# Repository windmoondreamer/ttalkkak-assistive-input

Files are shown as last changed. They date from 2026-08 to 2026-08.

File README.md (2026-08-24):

# OneGrip Play

한 손으로 PC 게임, Nintendo Switch, 웹 서핑과 미디어 조작을 할 수 있도록 만든 보조 입력기입니다. 손목·팔, 엄지, 검지·중지에 서로 다른 역할을 배분해 한 손 안에서 이동, 시점 조작, 버튼 입력을 함께 수행하는 것을 목표로 합니다.

> 현재 상태: 주요 기구부의 CAD와 자동 형상 검증, 전자부품 서비스 카세트, 전시용 A1 포스터까지 제작했습니다. 최종 실물 조립, 펌웨어 통합, 반복 내구시험과 대상 사용자 평가는 아직 진행해야 합니다.

<p align="center">
  OneGrip Play A1 전시 포스터
</p>

## 1. 개발 배경

양손 게임패드나 키보드·마우스는 이동, 시점, 액션 입력을 양손에 나눠 배치합니다. 다음과 같은 사용자는 손가락과 엄지를 움직일 수 있어도 이 입력들을 동시에 수행하기 어렵습니다.

- 편마비 또는 한쪽 상지의 기능 제한이 있는 사용자
- 한쪽 상지 절단으로 한 손 입력이 필요한 사용자
- 하반신 마비 등으로 침상이나 리클라이닝 자세에서 활동하는 사용자
- 팔을 넓게 움직이거나 양손 기기를 안정적으로 지지하기 어려운 사용자

OneGrip Play는 재활 효과를 주장하는 의료기기가 아니라, 게임과 디지털 여가에 접근할 수 있도록 돕는 보조 입력기 시제품입니다.

## 2. 현재 채택한 입력 구조

| 사용하는 부위 | 입력 장치 | PC 게임·Switch | 웹·미디어 |
|---|---|---|---|
| 손목·팔 | 하단 2축 짐벌 | 캐릭터 이동 | 메뉴 탐색 |
| 엄지 | 소형 조이스틱 | 시점 조작 | 포인터 이동·스크롤 |
| 검지·중지 | 8개 손가락 버튼 | 주요 액션 | 클릭·재생 제어 |

핵심은 입력 수를 무작정 늘리는 것이 아니라, 사용자가 이미 구분하기 쉬운 세 동작에 기능을 나누는 것입니다. 현재 통합안은 초기의 전체 QWERTY·트랙볼 구조가 아니라 **게임과 미디어에 필요한 핵심 입력을 우선한 구조**입니다.

## 3. 설계가 바뀐 과정

### 3.1 버티컬 키보드·트랙볼 탐색

처음에는 버티컬 마우스형 그립에 전체 문자 키와 엄지 트랙볼을 결합하는 방향을 검토했습니다. Half-QWERTY, 전체 물리 자판, U자형 키타워, 손가락별 3방향 스위치와 엄지 보조키 등 여러 배치를 비교했습니다.

그러나 전체 문자를 작은 그립에 넣으면 다음 문제가 생겼습니다.

- 키가 작아지고 인접 입력 가능성이 커짐
- 새로운 배열과 레이어 전환을 학습해야 함
- 손가락 독립성이 낮은 사용자에게 조작 부담이 커짐
- 멘토링에서 “적응하기 어려워 보인다”는 피드백을 받음

### 3.2 조종간형 뱅크 전환 탐색

본체를 좌우로 기울여 Bank A/B를 전환하고, 각 손가락에 좌·중앙·우 입력을 배치하는 조종간형 구조도 검토했습니다. 손가락 길이 차이, 지문 접촉 위치, 손바닥 지지, 중수골 스트랩, 엄지 도달 범위를 렌더로 반복 수정했습니다.

이 구조는 많은 문자를 넣을 수 있었지만 학습량과 기구 복잡도가 다시 증가했습니다. 이후 제품 목적을 문자 입력기에서 게임·미디어 보조 컨트롤러로 좁혔습니다.

### 3.3 OneGrip Play로 범위 축소

현재는 다음 원칙을 적용합니다.

1. 전체 키보드를 넣지 않는다.
2. PC 게임과 Nintendo Switch의 이동·시점·주요 액션을 우선한다.
3. 웹 서핑과 유튜브·OTT에 필요한 포인터·스크롤·클릭·재생 기능을 함께 제공한다.
4. 별도의 복잡한 문자 Bank 대신 기능 프로필로 입력을 매핑한다.
5. 커스텀 PCB 없이 완제품 개발보드와 직접 배선으로 시제품을 제작한다.

## 4. 인체공학 설계 기준

- 팔받침 각도: **20°**
- 손목만으로 기기를 지탱하지 않도록 전완 지지면을 넓게 구성
- 손을 퍼티에 쥔 듯한 곡면을 기준으로 손바닥과 손가락 접촉면 형성
- 손가락 길이 차이를 반영해 검지·중지 입력 위치를 다르게 배치
- 버튼을 누르기 위해 그립에서 손가락을 크게 떼지 않도록 구성
- 입력부를 교체 가능한 카세트로 분리해 손 크기와 스위치 공차를 조정 가능하게 설계

이 항목들은 CAD 설계 기준입니다. “인체공학적으로 최적”하다고 확정하려면 대상 사용자의 실제 손 자세, 압력 분포, 도달률과 피로도 시험이 필요합니다.

## 5. 기구 설계

### 5.1 검지·중지 8버튼 카세트

현재 통합 모듈은 검지 4키와 중지 4키로 구성됩니다.

- 기존 손가락 곡률과 버튼 중심을 유지
- 버튼 캡이 손가락 표면의 법선 방향으로 움직이도록 가이드 적용
- 검지와 중지를 각각 메인 3키와 측면 1키로 분리
- 깊은 스위치 홀더 대신 얕은 receiver와 내부 carrier 사용
- ITS-1105 실측값을 기준으로 스위치 포켓에 측면 여유 확보
- 공통 TPU rear pad로 스위치 후면을 지지
- FDM 출력 전 공차 쿠폰으로 스위치와 캡 끼워맞춤을 먼저 확인

자세한 제작 순서는 [`cad/onegrip-index-middle-cassette-v2/README.md`](cad/onegrip-index-middle-cassette-v2/README.md)에 정리했습니다.

### 5.2 3방향 손가락 모듈 연구안

별도 연구 브랜치에서는 검지·중지·약지·소지 각각에 LEFT/CENTER/RIGHT 독립 입력을 배치했습니다. 하나의 로커를 세 방향으로 쓰지 않고, 중앙 직선 플런저와 좌우 독립 회전 패들을 분리한 구조입니다.

최신 자동 검증 결과는 다음과 같습니다.

| 검증 항목 | 결과 |
|---|---:|
| 모듈 내부 최대 교차 부피 | 0.2787 mm³ |
| 인접 손가락 모듈 간 교차 부피 | 0.0 mm³ |
| B-rep 유효성 | 전 부품 통과 |
| hard stop 검증 | 4손가락 통과 |
| 종합 판정 | `overall_pass: true` |

이 결과는 CAD 형상 검증이며, 실제 입력 정확도나 피로도를 증명하지 않습니다. 자료는 [`cad/finger-input-v2-ergonomic/`](cad/finger-input-v2-ergonomic/)에 있습니다.

### 5.3 하부 2축 짐벌

하부 짐벌은 손잡이 전체를 움직여 이동 또는 메뉴 탐색 입력을 만드는 구조입니다.

- 20° 기울어진 원본 하우징 좌표계를 월드 좌표에 맞춰 조립
- 고정부와 가동부를 Blender 부모 계층으로 분리
- Ring과 Hub를 서로 다른 축의 피벗으로 구성
- 현재 Full Module V3 기준 기구 이동 범위는 축별 ±10°
- 고정 베이스 바닥에서 `HAND_REF`까지 85.153 mm
- 경사 데크에서 `HAND_REF`까지 법선 방향 55.879 mm
- 피벗은 착좌면보다 18.5 mm 아래에 위치

38개 출력 STL은 모두 closed manifold로 확인했습니다. ±10° 조합 자세에서 계산한 표면점 최소거리는 모두 양수였지만, 이는 정확한 솔리드 Boolean 보증이 아니라 샘플링 기반 근사입니다. 베어링 저널, 나사 물림, 스프링, Hall 센서와 중력 보상은 추가 검증이 필요합니다.

전체 조립 자료는 [`cad/onegrip-full-module-v3/`](cad/onegrip-full-module-v3/)에서 확인할 수 있습니다.

## 6. 전자부품 서비스 카세트

커스텀 PCB는 사용하지 않습니다. RP2040-Zero와 전원보드를 같은 높이에 나란히 배치하고, 사람이 직접 조립·수리할 수 있는 단층 카세트를 만들었습니다.

| 항목 | 설계값 |
|---|---:|
| 카세트 조립 외형 | 36 × 45 × 14 mm |
| RP2040-Zero 실측 | 17.92 × 23.15 mm |
| RP2040 포켓 | 18.42 × 24.35 mm |
| 전원보드 | 15.35 × 23.24 mm |
| 보드 배치 | 단층·나란히 배치 |
| 뚜껑 체결 | M3 수직 나사 4개 |

주요 수정 내용은 다음과 같습니다.

- 기존 매립 트레이와 2층 적층안은 조립·정비가 어려워 폐기
- RP2040 길이 방향 여유를 끝당 0.60 mm로 확대
- 전원보드 외부 단자 개구 삭제
- 두 보드를 카세트 위에서 독립적으로 넣고 뺄 수 있도록 설계
- 카세트 본체는 고정 `Base` 전면에 연결하고 뚜껑은 별도 부품으로 유지
- 원본 Base의 불필요한 후면 돌출부와 중앙 벽을 제거하고 데크 상면 단차를 수정
- 스프링 고정 보스 4개와 움직이는 귀 4개를 보존

카세트와 뚜껑은 별도 솔리드이며 같은 출력판에서 함께 출력할 수 있습니다. 카세트 부착부는 스톡 짐벌의 축별·대각선 ±20° 검사에서 가동부와 계산상 교차 부피 0 mm³를 기록했습니다.

남은 STOP 조건은 전원보드 하부 부품의 실제 XY 위치, 최고 부품 높이, 실제 USB-C 플러그 외형과 케이블 굽힘 반경입니다. 자세한 내용은 [`cad/electronics_service_cassette/README.md`](cad/electronics_service_cassette/README.md)를 참고하십시오.

## 7. 전자·펌웨어 방향

- 메인 제어기: RP2040-Zero
- 제작 방식: 커스텀 PCB 없이 개발보드·모듈·직접 배선 사용
- 손가락 입력: 디지털 스위치 직접 배선 또는 입력 확장 모듈 검토
- 하부 짐벌과 엄지 조이스틱: 아날로그 축 입력
- 대상 환경: Windows PC, Nintendo Switch, 웹·미디어 제어

현재 저장소에는 기구 설계와 전자부품 배치 검토가 중심적으로 들어 있습니다. 최종 HID 펌웨어, 플랫폼별 프로필, 연결 안정성 및 장시간 시험은 완료 상태로 표시하지 않습니다.

## 8. 검증 현황

| 항목 | 현재 상태 | 남은 작업 |
|---|---|---|
| 대상 사용자·사용 시나리오 | 정의 완료 | 장애인 멘토 대상 추가 인터뷰와 과제 관찰 |
| 20° 팔받침 외형 | CAD 반영 | 손 크기별 파지·압력 시험 |
| 검지·중지 8버튼 | CAD·공차 설계 | 공차 쿠폰, 스위치 조립, 연타·오입력 시험 |
| 3방향 손가락 연구안 | 자동 형상 검증 통과 | 실제 복귀력·피로·정확도 시험 |
| 하부 2축 짐벌 | 조립·좌표계·가동 시각화 | 베어링/나사/스프링/센서 실물 검증 |
| 서비스 카세트 | CAD·간섭 검증 및 실물 피드백 반영 | 전원보드 부품 높이와 케이블 굽힘 반경 확정 |
| PC·Switch 입력 | 요구사항 정의 | 펌웨어·프로필·실기 연결 시험 |
| 웹·미디어 제어 | 기능 매핑 정의 | 포인터·스크롤·재생 시나리오 시험 |
| 전시 자료 | A1 포스터 제작 완료 | 최종 실물 사진과 사용자 시험 결과 반영 |

## 9. 저장소 구조

```text
.
├─ cad/
│  ├─ onegrip-full-module-v3/          전체 조립과 하부 짐벌
│  ├─ onegrip-index-middle-cassette-v2/ 검지·중지 8버튼 카세트
│  ├─ finger-input-v2-ergonomic/       4손가락 3방향 연구안
│  ├─ electronics_service_cassette/    RP2040·전원보드 카세트
│  ├─ stock-cartridge-option-c/        스톡 짐벌 카트리지 검토
│  └─ source_snapshot/                  팀원·Claude 최소 재현 원본
├─ analysis/                            부품 배치와 간섭 탐색 스크립트·결과
├─ docs/                                기구 분석, BOM, 시험 계획, 보고서
├─ references/                          Lalboard 재현용 잠금 정보와 가져오기 스크립트
├─ renders/                             초기 아이디어와 설계 탐색 렌더
├─ 전시포스터/                         A1 PPTX·PDF·PNG와 생성 스크립트
├─ 팀원공유용/                          팀 공유 압축본
├─ 계획및부품안.md                     초기 현실 구현안
├─ 완전구현_설계및부품안.md            전체 구현 검토안
└─ RP2040_전원보드_배치검토.md          전자부품 배치 결정 과정
```

`renders/`에는 채택하지 않은 트랙볼·키타워·뱅크 전환안도 포함되어 있습니다. 현재 채택안을 확인할 때는 `cad/onegrip-full-module-v3/`, `cad/onegrip-index-middle-cassette-v2/`, `cad/electronics_service_cassette/`를 우선하십시오.

### 작업본 계보

현재 통합본은 한 작업자가 처음부터 다시 만든 형상이 아닙니다.

| 출처 | 반영된 내용 | 현재 위치 |
|---|---|---|
| 팀원 최신 OneGrip 작업본 | 우측 상부 쉘, 기존 엄지 버튼·조이스틱, 기준 조립 좌표 | `cad/source_snapshot/team_claude_latest/` |
| Claude Code 체크포인트 | 검지·중지·엄지 구조 분석, 20° 하부 매립 짐벌과 검증 데이터 | 최소 원본 스냅숏과 `cad/onegrip-full-module-v3/` |
| 현재 통합·수정 작업 | 검지·중지 8버튼 V2, 짐벌 고정/가동 보정, 서비스 카세트, 포스터 | `cad/`, `analysis/`, `전시포스터/` |

GitHub에서 전체 모듈을 다시 만들 때 Desktop의 원래 작업 폴더가 없어도 되도록,
빌드에 실제로 필요한 18개 원본 파일을 저장소 내부에 포함했습니다. 자세한 범위와
해시는 [`cad/source_snapshot/team_claude_latest/README.md`](cad/source_snapshot/team_claude_latest/README.md)에 기록했습니다.

## 10. 주요 산출물

- 전체 모듈 패키지: [`OneGrip_Full_Module_RH_V3_EMBEDDED_GIMBAL.zip`](OneGrip_Full_Module_RH_V3_EMBEDDED_GIMBAL.zip)
- 검지·중지 카세트 패키지: [`OneGrip_IndexMiddle_Cassette_V2.zip`](OneGrip_IndexMiddle_Cassette_V2.zip)
- A1 전시 포스터: [`전시포스터/OneGrip_Play_A1_전시포스터.pdf`](전시포스터/OneGrip_Play_A1_전시포스터.pdf)
- 인쇄용 포스터 PNG: [`전시포스터/OneGrip_Play_A1_전시포스터_인쇄용.png`](전시포스터/OneGrip_Play_A1_전시포스터_인쇄용.png)
- 전자부품 배치 검토: [`RP2040_전원보드_배치검토.md`](RP2040_전원보드_배치검토.md)

대용량 ZIP은 소스와 중복되므로 Git 저장소에 계속 누적하기보다 GitHub Releases에 배포하는 편이 적합합니다.

## 11. 다음 단계

1. ITS-1105 공차 쿠폰과 검지 버튼 1세트를 먼저 출력합니다.
2. RP2040 길이 공차 쿠폰에서 끝당 0.50/0.60/0.70 mm를 실물 비교합니다.
3. 전원보드 상·하부 부품 높이와 USB 플러그 외형을 실측합니다.
4. 하부 짐벌의 베어링 저널, 나사 체결, 스프링과 센서 구조를 확정합니다.
5. RP2040 펌웨어에서 입력 스캔, 데드존, 디바운스와 플랫폼 프로필을 구현합니다.
6. PC와 Nintendo Switch에서 이동·시점·액션 동시 입력을 시험합니다.
7. 웹 서핑과 유튜브·OTT에서 포인터·스크롤·클릭·재생 과제를 시험합니다.
8. 장애인 멘토와 함께 도달 실패, 오입력, 피로, 통증 위치를 기록하고 손 크기별 부품을 수정합니다.

## 12. 참고 설계와 라이선스

손가락 입력 구조를 검토할 때 JesusFreke의 [Lalboard](https://github.com/JesusFreke/lalboard)를 참고했습니다. OneGrip의 CAD와 형상은 별도로 작성했으며 Lalboard 메시나 Python 형상을 복사하지 않았습니다.

재현 가능한 참조 커밋과 Apache License 2.0 고지는 다음 파일에 정리했습니다.

- [`NOTICE-THIRD-PARTY.md`](NOTICE-THIRD-PARTY.md)
- [`references/reference-lock.json`](references/reference-lock.json)
- [`THIRD_PARTY_LICENSES/lalboard-Apache-2.0.txt`](THIRD_PARTY_LICENSES/lalboard-Apache-2.0.txt)

저장소 전체에 적용할 프로젝트 라이선스는 별도로 확정해야 합니다. 제3자 고지 파일은 프로젝트 전체 라이선스를 대신하지 않습니다.

## 13. 팀

동국대학교 전자전기공학부  
김민섭 · 윤홍민 · 장재원 · 김예진

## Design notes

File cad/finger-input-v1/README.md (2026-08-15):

# OneGrip Play — 3방향 손가락 입력 카트리지 V1

## 결론

이 디렉터리는 검지·중지·약지·소지 각각에서 손끝 위치를 거의 유지한
채 `LEFT / CENTER / RIGHT`를 입력하는 실제 파라메트릭 CAD와 출력물을
담는다. V1 우선안은 **Variant B 독립 3패들**이다.

- LEFT / RIGHT: 서로 독립된 금속축 회전 패들 + 수직 가이드 팔로워
- CENTER: 회전하지 않는 2점 가이드 직선키
- 센서: Panasonic `EVQ-P0E07K` 3개/카트리지
- 스위치는 신호만 검출하며, 최대 하중은 PETG 셸 하드스톱이 받는다.
- 각 카트리지는 나사로 분리·교체하며 본체를 다시 출력하지 않는다.
- 소지는 검지 STL의 단순 축소가 아니라 별도 폭·레버비·힘 프리셋이다.

이 설계는 P0 제작 전 CAD 검증본이다. 사람에게 맞는지와 95% 입력 정확도는
아직 실물 시험으로 확인해야 하므로 임상적으로 검증됐다고 표현하면 안 된다.

## Lalboard에서 참고한 것과 바꾼 것

공식 Lalboard v2.5.1 소스와 그 소스가 가리키는 3MF를 조사했다. 참고한 것은 중앙 기준점, 독립된
방향키, 짧은 fingertip roll, 오목한 접촉면, 로컬 피벗과 손가락별 조절 원리다.
OneGrip용 원본 CAD를 새로 작성했으며 upstream mesh나 생성 코드는 복사하지
않았다.

제거·변경한 요소:

- 5입력 → LEFT/CENTER/RIGHT 3입력
- 광학 센서·자석·커스텀 PCB → 일반 저압 택트 스위치와 직접 배선
- 3점 자석식 6자유도 지지 → 교체식 카트리지와 별도 슬롯 마운트
- Lalboard의 매우 작은 PLA 공차 → 0.4mm 노즐 PETG 시작 공차

상세 분석과 라이선스는
[`../../docs/lalboard_analysis.md`](../../docs/lalboard_analysis.md)와
[`THIRD_PARTY_NOTICES.md`](THIRD_PARTY_NOTICES.md)를 참고한다.
고정한 upstream 커밋과 재생성 절차는
[`../../references/README.md`](../../references/README.md)에 있다.

## 디렉터리

```text
cad/finger-input-v1/
├─ finger_module_common.py        파라메트릭 CAD 원본
├─ finger_module_{index,middle,ring,pinky}.py
├─ variant_{a,b,c}_*.py           비교안 진입점
├─ generate_all.py                전체 재생성
├─ tolerance_coupon.py            PETG 공차 쿠폰
├─ validate_geometry.py           형식·메시·기구 검증
├─ render_previews.py             Blender 5 렌더 생성
├─ printable/                     개별 출력 부품 STL/STEP/3MF + 조립체 STEP/3MF
├─ variants/                      A/B/C 개별 부품과 조립체 CAD
├─ test_fixture/                  P0 높이·각도 조절 지그
├─ integration/                   4손가락 배열 CAD
├─ renders/                       30개 PNG, Blender 장면, 시각화 전용 메시 캐시
└─ reports/                       자동 검증 결과
```

## 산출물 형식 정책

- **개별 출력 부품**은 `STL / STEP / 3MF` 세 형식을 제공한다. 실제 출력에는
  `printable/`, `test_fixture/`, `integration/`, `variants/`의 부품별 STL을 쓴다.
- `*_assembly`, `fixture_with_middle_module`, `four_finger_array`,
  `four_finger_array_with_attached_rail`처럼 서로 접촉하는 여러 부품을 한 파일에
  담은 **조립체의 권위본은 STEP/3MF**다. 조립체 STL은 배포하지 않으며 조립체를
  한 덩어리로 출력해서도 안 된다.
- [`renders/geometry_cache/`](renders/geometry_cache/)의
  `*_visualization_only.stl`은 Blender가 빠르게 읽도록 여러 솔리드를 평탄화한
  **시각화 전용 캐시**다. 접촉 경계 때문에 인쇄용 watertight 메시를 보장하지
  않으므로 출력·치수 검증·제작 전달에 사용하지 않는다.
- 형상이 서로 다르게 보일 경우 개별 부품은 STEP/3MF와 해당 부품 STL을,
  조립 관계는 STEP/3MF를 기준으로 판단한다.

## 손가락별 시작값

| 손가락 | 유효 폭 | 중앙 캡 | 카트리지 외함 | 측면 레버비 | 계산 손끝 힘 | 계산 측면 이동 | 본체 배치 Z / 깊이 |
|---|---:|---:|---:|---:|---:|---:|---:|
| 검지 | 21.0mm | 9.5mm | 35×32mm | 1.35 | 0.548N | 0.837mm | 116 / -3mm |
| 중지 | 22.0mm | 9.5mm | 35×32mm | 1.40 | 0.529N | 0.868mm | 86 / 0mm |
| 약지 | 20.5mm | 8.5mm | 35×32mm | 1.50 | 0.493N | 0.930mm | 57 / -3mm |
| 소지 | 18.5mm | 7.5mm | 35×32mm | 1.65 | 0.448N | 1.023mm | 30 / -8mm |

측면 압력 방향은 카트리지의 `X`, 손가락 길이는 `Y`, 지문면 법선은 `Z`다.
소지 패들은 더 좁고, 스위치에 대한 접촉점 지렛팔이 더 길어 같은 스위치로도
손끝 작동력을 낮춘다.

## P0에서 우선 출력할 파일

전체 네 카트리지를 한 번에 출력하지 않는다. 아래 순서로 진행한다.

1. `test_fixture/petg_tolerance_coupon.stl`
   - 하드스톱 보정은 `hard_stop_shim_0.1mm.*`, `hard_stop_shim_0.2mm.*`,
     `hard_stop_shim_0.3mm.*`도 함께 준비한다.
2. `test_fixture/fixture_base.stl`
3. `test_fixture/fixture_carrier.stl`
4. `printable/index_cartridge.stl`
5. `printable/index_bottom_cover.stl`
6. `printable/index_left_key.stl`
7. `printable/index_left_follower.stl`
8. `printable/index_center_key.stl`
9. `printable/index_right_follower.stl`
10. `printable/index_right_key.stl`
11. 필요하면 `index_*_tpu_pad.stl`

`fixture_with_middle_module.step/.3mf`와 `*_assembly.step/.3mf`는 조립 위치를
확인하는 권위본이며 한 덩어리로 출력하는 파일이 아니다. 같은 장면의
`renders/geometry_cache/*_visualization_only.stl`은 렌더 전용이다.

## 대표 렌더

Variant B의 실제 분리 부품, 작동 상태와 네 손가락 통합 배치를 먼저 확인한다.
모든 이미지는 위 형식 정책에 따라 생성한 시각화 자료이며 제작 치수의 권위본은
CAD STEP/3MF다.

Variant B 분해도

Variant B LEFT 작동 상태

네 손가락 배열과 M 그립 통합 프리뷰

## 권장 출력 조건

### PETG 셸·키

- 0.4mm 노즐, 0.2mm 층
- 외벽 4줄, 상·하 5층 이상
- 25~35% gyroid/cubic infill
- 키 뿌리와 피벗 주변은 5벽 또는 modifier로 60% 이상
- 치수 우선: XY 보정·elephant-foot 보정을 먼저 쿠폰에서 결정
- 축 구멍은 서포트와 맞닿지 않게 배치하고 출력 뒤 Ø2.4mm 리머/드릴로
  손으로 정리한다. 전동 공구로 구멍을 크게 만들지 않는다.

### TPU 패드

- TPU 95A, 0.2mm 층, 외벽 3줄
- 패드는 선택 사항이다. PETG 키만 먼저 시험해 경계가 불분명하거나 피부
  압박이 있을 때 붙인다.
- 순간접착제로 영구 고정하기 전에 얇은 양면테이프로 두께를 비교한다.

### 서포트

- 셸: 평평한 바닥면을 베드에 두면 내부 6.6mm 브리지만 남는다. 일반적인
  튜닝 프린터에서는 무서포트 시작안이다.
- 바닥 커버·마운트·쿠폰: 무서포트.
- 패들 키: 피벗 축을 수평으로 놓으면 원통 하부 품질이 나빠질 수 있으므로
  슬라이서에서 키를 옆면으로 눕히고 빌드플레이트 한정 유기 서포트를 피벗
  배럴에만 허용한다. 첫 P0에서는 0.15mm와 0.20mm 접촉 여유를 모두 시험한다.

## 필요한 기계 부품 — 한 카트리지

- EVQ-P0E07K 3개
- Ø2.0mm 스테인리스 축 2개, 각 약 14.5mm
- Ø1.0mm 스테인리스 anti-loss pin 2개, 각 약 4mm
- M2 바닥 커버 나사 4개와 M2 insert 4개
- M3 카트리지 장착 나사 2개와 insert/너트
- JST-SM 4P pigtail 1세트
- 26~28AWG 연선 4가닥: LEFT, CENTER, RIGHT, COMMON GND

완전 BOM과 공식 전기 조건은
[`../../docs/finger_module_bom.md`](../../docs/finger_module_bom.md)에 있다.

## 조립 순서

1. 공차 쿠폰에서 축 구멍과 이동 간극을 선택한다.
2. 셸의 스위치 포켓, 배선 홈, 축 구멍만 정리한다. 키 접촉면을 사포로 임의
   변경하지 않는다.
3. CENTER 키의 두 post를 guide에 넣고 Ø1mm anti-loss pin 두 개를 측면
   슬롯으로 삽입한다. 핀은 키와 함께 0.62mm 이동해야 한다.
4. LEFT/RIGHT 키를 pivot ear 사이에 두고 Ø2mm 축을 끼운다. 축 끝은 E-clip,
   얇은 열수축튜브 또는 나사 고정용 소형 collar로 이탈을 막는다.
   각 키 아래에는 같은 방향의 수직 팔로워를 가이드에 먼저 넣는다.
5. 셸을 뒤집어 스위치 3개를 각 포켓에 넣는다. `C/NO` 두 단자를 사용한다.
6. 세 스위치의 한쪽 단자를 GND로 묶고 나머지를 L/C/R 신호선으로 납땜한다.
7. 배선을 홈에 눕히고 rear exit 뒤에 열수축튜브 또는 케이블 타이로 strain
   relief를 만든다. 움직이는 키·축과 배선이 닿으면 안 된다.
8. 바닥 커버를 M2 나사로 조인다. 스위치가 흔들리지 않을 만큼만 조이며,
   커버로 스위치 몸체를 변형시키지 않는다.
9. 무부하 100회 복귀와 멀티미터 연속성 검사를 한 뒤 지그에 M3로 장착한다.

## 배선

```text
JST-SM 4P
1  BLACK  COMMON GND ─┬─ switch L
                     ├─ switch C
                     └─ switch R
2  BLUE   LEFT signal
3  WHITE  CENTER signal
4  YELLOW RIGHT signal
```

MCP23017은 3.3V 입력과 풀업으로 읽고 기구 시험에서는 ON 5ms / OFF 10ms stable debounce를
같게 적용한다. 펌웨어 상호잠금으로 기구 오입력을 숨기지 않는다.

## 하드스톱과 조정

- EVQ-P0E07K 최대 pretravel 0.50mm
- CAD 기본 stop gap: 0.62mm. 실제 작동거리를 실측한 뒤 `작동거리 + 0.10~0.12mm`가 되도록 U-shim으로 줄임
- center 총 stroke: 0.62mm 직선 이동
- side switch 지점 이동: 0.62mm; 손끝에서는 레버비에 따라 0.84~1.02mm
- 축 지름: Ø2.0mm; CAD 축공 Ø2.4mm(직경 0.4mm 시작 여유)
- 스위치 포켓: 실물 외형에서 면당 0.20mm 시작 여유

스위치를 먼저 넣고 키가 바닥까지 계속 눌리는 경우 P0를 중단한다. 스위치가
구조 스토퍼가 된 것이므로 셸 랜딩 또는 0.1/0.2/0.3mm shim으로 하드스톱을
앞당긴다.

## 테스트

1. 멀티미터로 L/C/R 독립성을 확인한다.
2. 중립 60초 자동 입력이 없어야 한다.
3. 방향별 30회, 총 90회 무작위 입력을 기록한다.
4. CENTER 4Hz, LEFT/RIGHT 3Hz 반복 시험을 한다.
5. 같은 지그에서 A/B/C를 비교하고 소지를 별도 확인한다.

정확한 판정식과 P0/P1/P2 Gate는
[`../../docs/finger_module_test_protocol.md`](../../docs/finger_module_test_protocol.md)를
따른다.

## 재생성

Python 3.12와 `requirements-cad.txt`를 사용한다.

```powershell
python -m pip install -r cad/finger-input-v1/requirements-cad.txt
python cad/finger-input-v1/generate_all.py
python cad/finger-input-v1/tolerance_coupon.py
python cad/finger-input-v1/validate_geometry.py
```

Blender 5 렌더:

```powershell
& 'C:\Program Files\Blender Foundation\Blender 5.0\blender.exe' `
  --background --python cad/finger-input-v1/render_previews.py
```

## 현재 알려진 한계

- CAD의 손가락 surrogate는 인체 계측 proxy일 뿐 실제 사용자 손이 아니다.
- M 그립 통합은 대략 배치로, 실제 체결용 벽·나사 보스·손바닥/엄지 clearance는
  P1/P2 뒤 본체 CAD에 반영해야 한다.
- 자동 검증은 파일 형식·솔리드 간섭·캠/팔로워 접촉·유지핀 이동창·단자 relief·마운트 범위를 확인한다. 스위치 편차, PETG
  크리프, 피부 압력, 경직·떨림, finger enslaving은 실물 시험이 필요하다.
- 자동 형식 검증의 STL 대상은 개별 출력 부품이다. 조립체는 STEP/3MF의 독립
  솔리드를 검사하며 `renders/geometry_cache`의 평탄화 STL은 검증·출력 대상에서
  제외한다.
- 측면 패들 회전은 약 7.75°다. 소지 손끝 이동은 약 1.02mm지만, 실제
  촉각 경계가 불명확하면 소지 피벗/스위치 위치를 P0 데이터로 바꿔야 한다.
- 8월 16일까지 B안이 P0 Gate를 통과하지 못하면 C안을 튜닝하지 않고 A안으로
  전환한다.

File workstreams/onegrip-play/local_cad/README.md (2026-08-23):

# OneGrip Play local-first CAD

이 디렉터리는 Onshape와 독립된 로컬 CAD 작업의 경계를 정의한다.

- `reference/`: immutable upstream geometry의 위치와 사용 규칙
- `manifests/`: 해시, 크기, 수정 시각, BBox, solid/component 검증 결과
- 향후 `middle/`, `thumb/`, `integration/`, `output/`: build123d source와 generated output

정책:

1. upstream STEP/STP는 원본 그대로 보존한다.
2. STL은 mesh sanity/reference 또는 제조 출력으로만 사용한다.
3. 신규 형상은 build123d Python source에서 생성한다.
4. baseline STEP과 generated STEP/STL을 같은 파일에 덮어쓰지 않는다.
5. 이 디렉터리의 작업은 Onshape API, browser automation, CAD write를 요구하지 않는다.

현재 MIDDLE shell docking은 JaD/JfD shell STEP 부재로 STOP 상태다. 상세 판정은
`docs/44_local_middle_shell_docking.md`를 따른다.

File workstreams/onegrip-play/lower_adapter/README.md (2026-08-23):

# lower_adapter — 하부 경사 어댑터 서브시스템

OneGrip 상체(그립)를 **무수정 탈착 모듈**로 두고, 그 아래에 경사 마운트와 미래 X/Y 짐벌
인터페이스를 새로 만드는 작업 전용 폴더다.

상체(검지/중지 버튼·holder·retainer) 워크플로와 **완전히 분리**되어 있다.
루트의 `docs/` · `cad/` · `scripts/` 는 상체 전용이고, 이 폴더가 하부 전용이다.

> 분리 이유: 두 워크플로가 병렬로 돌아가면서 루트 `docs/` 번호가 충돌했다
> (`docs/31` 이 상체 스위치 감사와 하부 분석 양쪽에서 동시에 쓰였다).
> 하부 문서는 이 폴더 안에서 `00_` 부터 독립 번호를 쓴다.

---

## 폴더

```
lower_adapter/
├── README.md
├── docs/
│   ├── 00_architecture_analysis.md   # 아키텍처 사전 분석 (READ ONLY, CAD WRITE 0건)
│   ├── 01_adapter_v1_implementation.md
│   ├── 02_embedded_gimbal_architecture.md
│   ├── 03_embedded_gimbal_v1.md      # OPTION B (fallback, 보존)
│   ├── 04_chassis_cleanup_validation.md
│   ├── 05_stock_cartridge_feasibility.md
│   ├── 06_stock_cartridge_v1.md      # OPTION C thin-deck (참조 상태)
│   ├── 07_conformal_stock_embed_v1.md  # 컨포멀 매립 코어 (동결)
│   └── 08_ergo_wrist_shell_w2.md     # ★ W2 손목 받침 외피 (현재 활성)
├── cad/
│   ├── OneGrip_LowerAdapter.fs       # 어댑터 FeatureScript (stage A~H)
│   ├── OneGrip_EmbeddedGimbal.fs     # OPTION B (fallback, 보존)
│   ├── OneGrip_Cartridge.fs          # OPTION C thin-deck (참조)
│   ├── OneGrip_Conformal.fs.tmpl     # ★ 컨포멀 템플릿 (상수는 생성기가 주입)
│   ├── OneGrip_Conformal.fs          # 컨포멀 코어 (동결)
│   ├── OneGrip_Ergo.fs.tmpl          # ★ W2 외피 템플릿
│   └── OneGrip_Ergo.fs               # ★ 생성 결과
│   └── _profiles.fs.inc              # 생성된 플랜지 윤곽 72점
├── scripts/
│   ├── analyze_lower_interface.py    # 00 문서의 모든 수치를 재생성
│   ├── gen_adapter_constants.py      # FS 상수 생성 + 사전 검증
│   ├── run_adapter.py                # 단계별 실행기 (상체 eid 차단 가드 포함)
│   ├── verify_adapter.py             # 최종 검증 (20도 / 물림 / 간섭 / 스택)
│   ├── shots.py                      # 렌더 + 측면 합성도
│   └── fs_probe.py                   # FeatureScript 오류 진단 보조
└── cad_dump/                         # 이 서브시스템 전용 파생 데이터
    ├── bot_first.npy / bot_n.npy     # 바닥면 +Z 레이캐스트 맵 (1.0 mm)
    ├── socket_first.npy / _last.npy  # 소켓 영역 정밀 맵 (0.25 mm)
    ├── flange_outline.npy            # 플랜지 윤곽 폐곡선 (360 pt)
    ├── outer_prof.npy                # Z별 외피 반경 프로파일
    ├── asm_transforms.json/.npy      # Complete assembly occurrence transform
    ├── adapter_constants.json        # FS 상수 + 사전 검증 결과
    ├── mesh_CRADLE/WEDGE/RING_*.json  # 생성된 어댑터 tessellation
    ├── mesh_LIVE_JaD/JfD.json         # ITS-1105 이후 상체 (하단 무변화 확인용)
    ├── shot_iso/top/composite_side.png
    └── verify_out.txt                 # 최종 검증 전문
```

**메시 원본(`mesh_*.json`)은 루트 `cad_dump/` 에 그대로 둔다.** 두 워크플로가 공유하며
이 폴더의 스크립트는 읽기만 한다.

## 재현

```bash
python lower_adapter/scripts/analyze_lower_interface.py
```

`--fetch-asm` 을 붙이면 Onshape assembly transform 을 다시 GET 한다 (그 외에는 캐시 사용).
GET 전용이며 POST/PUT/DELETE 를 하지 않는다.

---

## 확정된 것

| 항목 | 값 | 근거 |
|---|---|---|
| ONEGRIP_CENTER_AXIS | (0.000000, 27.269160) 을 지나는 grip +Z | 보어 41단면, +Z 편차 0.000000° |
| MOUNT_ORIGIN | (0.000000, 27.269160, −67.878507) | 중심축 × 플랜지면 |
| 착좌면 | 평면 1개, 5017.5 mm², 77.43 × 72.44 mm | 3901점 적합, residual 6.4e-05 mm |
| 착좌면 ⟂ 중심축 | **0.000000°** (이미 성립) | 평면적합 vs 보어축 |
| 소켓 보어 | 21.072 × 25.672 × 직진 21.000 mm | 실측 |
| 상대 post | 20.272 × 25.272, 여유 X 0.40 / Y 0.20 mm/side | assembly transform |
| 보스 | 31.0 × 35.5, 아래로 6.000 mm | 실측 |
| `#grip_tilt` | **20°** (15/25/30 파라미터화) | 사용자 지정 |
| `#tilt_direction` | **TOP → −Y**, `RotX(+θ)`, n = (0, −0.342020, 0.939693) | 사용자 확정 ("엄지는 위쪽") |
| `#hand_sign` | +1 (RIGHT HAND) | 사용자 확정. 경사와 독립 |

## 구조 방침

```
[ OneGrip 상체 ]  <- 무수정
      |   평면 착좌 + 보스 포켓 + post 복제 + 클램프 링
[ A. Grip Cradle ]   각도 무관, 정밀 피처 전부
      |   4xM3 평면 조인트
[ B. Tilt Wedge ]    15/20/25/30 deg, 각도 의존은 여기뿐
      |   수평 인터페이스 (동결 스펙)
[ 미래 X/Y 짐벌 ]
```

## 현재 상태

- **★ 현재 활성: W2 손목 받침 인체공학 외피 -> `docs/08_ergo_wrist_shell_w2.md`**
  - 체크포인트 `PRE_ERGO_SHELL` = `8099b51b080d7e6963fb0068`
  - 신규 Part Studio `OneGrip_ErgoShell` = `a2e4739a4d624b06dee5abba`
  - `ERGO_SHELL` 634,810mm3 + `BOTTOM_CARRIER` 90,178mm3, 검증 28/28 PASS
  - 외형 128.6 x 219.7 x 139.9, 손목 받침 7,173mm2 @ 7.0deg
  - **HAND_REF 변화 0 / 돌출 0 / 코어 무수정**
  - ⚠ **결과 버전 미생성 + 마지막 FS 업로드 미검증** (Onshape API 402). docs/08 §7 참조
- 스톡 짐벌 컨포멀 매립 하우징 (코어, 동결) -> `docs/07_conformal_stock_embed_v1.md`
  - 체크포인트 `PRE_CONFORMAL_STOCK_EMBED` = `ab593a676cb73163260c50e5`
  - 결과 버전 `CONFORMAL_STOCK_EMBED_V1` = `42a15b14ff576623e223b7c6`
  - 신규 Part Studio `OneGrip_ConformalHousing` = `8945f7ac4100dfd52a8c8dba`
  - `CONFORMAL_HOUSING` (JHD) 128.6x170.6x139.9 / `BOTTOM_CARRIER` (RdKD) 118x123x9
  - **STOCK_PROTRUSION_BELOW_FINAL_HOUSING = 0.0000 mm**
  - 경사면 -> HAND_REF **55.8785 mm** (thin-deck 와 동일), 지면 -> HAND_REF 161.0208 mm
  - 검증 26/26 PASS. 커스텀 짐벌은 **개발 중단, 참고자료로만 보존**
- OPTION C thin-deck (비교/참조 상태) -> `docs/06_stock_cartridge_v1.md`. 검증 32/32 PASS.
  - 체크포인트 `PRE_STOCK_CARTRIDGE` = `f4503217c4b324ef98447bc6`
  - 결과 버전 `STOCK_CARTRIDGE_V1_VALIDATED` = `2e661ad4e1f5970dee79371d`
  - 신규 Part Studio `OneGrip_StockCartridge` = `f698b10ce216ca7c95051dd3`
  - `CARRIER_PLATE` (JHD) 117.6x117.6x9.0 / `DECK_HOUSING` (R/CD) 130x130
  - 덱 -> HAND_REF **55.8785 mm**, 지면 -> HAND_REF 161.0208 mm, 20.000000 deg
  - **스톡 짐벌 수정 0건.** 나사 2개를 M3x16 -> M3x22 로 교체하는 것만 필요
- 스톡 짐벌 카트리지(OPTION C) 실현성 감사 -> `docs/05_stock_cartridge_feasibility.md`
  (CAD WRITE 0건). **권고 = OPTION C**, 조건 = 덱 아래 약 115 mm 확보.
  매립형(OPTION B)은 **중단이지 폐기가 아니다** — fallback 으로 보존한다.
  정정: 원본 스톡 높이 122.47 -> **82.078 mm**, 풋프린트 -> **100.0 x 143.0 x 18.5 mm**
- **매립형 짐벌 1차 CAD 완료** → `docs/03_embedded_gimbal_v1.md`
  - 버전 `EMBEDDED_GIMBAL_V1` = `239edc28544c9978899ed7a1`
  - Part Studio `OneGrip_EmbeddedGimbal` = `2e024442c796323fd37e49c3` (body 5)
  - `#pivot_depth` **18.5 mm** / `#gimbal_travel` **10 deg** (변수로 조정 가능)
  - 간섭 0, 20.000000°, 경사외피→HAND_REF **55.879 mm**, 베이스→HAND_REF **85.153 mm**
- 아키텍처 비교/패키징 한계 → `docs/02_embedded_gimbal_architecture.md`
- (구) 적층형 어댑터 → `docs/01_adapter_v1_implementation.md`
- 체크포인트 `PRE_ADAPTER` = `40aeafabde5ccb638fa0aec3`
- 결과 버전 `LOWER_ADAPTER_V1` = `41712f1bb7b025dbdb8b67b4`
- 신규 Part Studio `OneGrip_LowerAdapter` = `bbfebe9c42748fb6d5b912e8` (피처 8 / solid 4)
- **상체 Joystick Part Studio 쓰기 0건** — 신규 스튜디오에 derive 가 없어 구조적으로 불가
- 검증 전 항목 PASS: 20.000000° / 물림 20.000mm / 간섭 0 / 최소 살 3.250mm / 스택 33.900mm
- **다음 단계(짐벌)는 별도 승인 필요**

## 이월된 미결

- 정적 편심: 확정 방향에서 CG 편차 −45.596 mm (원본 수직 −26.817 의 1.70배).
  전도 모멘트 약 4020 → 6840 g·mm (1.70배). 기하로는 상쇄 불가.
  **이번 어댑터 단계에서는 보상하지 않는다** (사용자 지시). 어댑터 물리 확정 →
  최종 가동질량 확정 → 실제 스프링 선정·실측 → 짐벌 피벗 확정 이후에 결정한다.
  **Hall 오프셋은 보상 수단이 아니다** — 전기적 중심만 옮길 뿐 중력 토크를 상쇄하지 못한다
- `#gimbal_bolt_pattern` 동결 시점
- FDM 프린터·재료 (`#fdm_clearance`)
- post 밑동 2.008 × 2.5 mm 관통 슬롯의 기능 (복제 여부)

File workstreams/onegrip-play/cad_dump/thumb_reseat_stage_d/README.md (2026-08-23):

# Do not use `Joystick_1_stage_d.stl`

The STL in this folder was copied from an older browser download while testing
the Onshape export UI.  Its timestamp predates the THUMB reseat write and it is
**not** a Stage-D export.  It is excluded from every audit and render.

The authoritative result is the live Main workspace plus
`cad_dump/thumb_reseat_final_audit.json`.

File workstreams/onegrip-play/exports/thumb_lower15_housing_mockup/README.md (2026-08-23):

# OneGrip lower-15 external housing mockup

Source: Onshape `OneGrip_Play_V1 / Main / Joystick`  
Saved CAD version: `THUMB_LOWER15_HOUSING_V1`  
Configuration: `default`  
Unit: millimetre

## Print parts

- `OneGrip_lower15_housing_Joystick_1_JaD.stl`
- `OneGrip_lower15_housing_Joystick_2_JfD.stl`

These are the two complete external shell bodies only. Buttons, Backplate,
joystick hardware, INDEX/MIDDLE switch parts, retainers, wiring, and all other
internal components are excluded.

Import both STL files into the slicer as separate objects with scaling disabled.
Do not merge overlapping meshes: the two files are the mating shell halves.
Each shell occupies approximately `38.735 × 123.855 × 152.127 mm` in the source
coordinate frame, so rotate each half to suit the printer's usable volume and
support strategy.

## Mesh gate

Both STL files passed:

- one connected component per file
- watertight mesh
- consistent winding
- non-two-manifold edges: 0
- degenerate triangles: 0

See `mesh_validation.json` for exact counts, bounds, and volume.

This package is for external-form and shell-assembly mockup verification. The
internal hardware and INDEX/MIDDLE redesign are deliberately deferred.

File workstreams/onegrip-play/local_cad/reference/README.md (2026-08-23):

# Immutable reference policy

현재 저장소에서 발견된 주 shell reference는 다음 STL이다.

- `exports/thumb_lower15_housing_mockup/OneGrip_lower15_housing_Joystick_1_JaD.stl`
- `exports/thumb_lower15_housing_mockup/OneGrip_lower15_housing_Joystick_2_JfD.stl`

두 파일은 원본을 덮어쓰지 않는 immutable mesh reference다. 둘 다 watertight한 단일
mesh이지만 OCCT solid가 아니므로 production shell boolean의 baseline으로 승격하지
않는다.

필수 보완 reference:

- JaD shell STEP/STP (millimetre, current intended baseline)
- JfD shell STEP/STP (millimetre, current intended baseline)

추가 권장 reference:

- screw/boss exact B-rep 또는 screw center/axis/radius/depth registry
- original THUMB rigid module STEP

새 reference가 들어오면
`build123d_workbench/inventory_local_references.py`를 다시 실행해 manifest를 갱신한다.

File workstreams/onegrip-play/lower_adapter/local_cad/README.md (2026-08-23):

# local_cad — 로컬 build123d 인체공학 외피 작업공간

하부 **인체공학 외피(ergonomic outer shell)** 개발을 Onshape API 의존에서 떼어내
로컬 파라메트릭 CAD 로 옮긴 작업공간이다.

```
검증된 Onshape 기계 형상
        ↓  STEP 으로 동결 (수동 export)
로컬 build123d / OpenCascade
        ↓
인체공학 하우징 개발
        ↓
STEP + STL + BREP 출력
```

```
ONSHAPE_API       = FORBIDDEN
LOCAL_CAD_ENGINE  = build123d
CUSTOM_GIMBAL     = FORBIDDEN
APPROXIMATE_CORE_REBUILD = FORBIDDEN
```

이 폴더 안에서는 **Onshape API 를 호출하지 않는다.** Onshape 는 STEP 을 수동으로
내보내기 위한 원본 저장소일 뿐이다.
상체(손가락 버튼) 워크플로는 이관 대상이 아니며 기존 위치에 그대로 둔다.

---

## 현재 상태

**Phase 0 완료 · 동결 레퍼런스 STEP 대기 중.**

| | |
|---|---|
| build123d | **0.11.1** (venv python 3.12.13, OCP `cadquery-ocp-novtk` 7.9.3.1.1) |
| 스모크 테스트 | **PASS 7/7** — primitive / boolean / fillet / loft / export / roundtrip / STL |
| STEP 왕복 | **PASS** — bbox 오차 1.42e-14 mm, 부피 상대오차 3.92e-14 |
| 저장소 STEP/BREP | **0개** → 형상 작업 미착수 |

**저장소에 STEP / BREP / FCStd 가 하나도 없다.**
지시 §8 / STOP 조건에 따라 근사 치수나 tessellation 캐시로 기계 코어를 재구성하지
않고 멈춰 있다.

필요한 파일과 정확한 내보내기 방법:
**[`reference/STEP_EXPORT_REQUEST.md`](reference/STEP_EXPORT_REQUEST.md)** (CAD 엔진과
무관한 내용이라 CadQuery→build123d 전환과 상관없이 그대로 유효하다)

```
필수   STOCK_GIMBAL_REFERENCE.step
       CONFORMAL_CORE_REFERENCE.step        <- 가장 중요
       ONEGRIP_LOWER_ASSEMBLY_REFERENCE.step
선택   ONEGRIP_REFERENCE.step
       ELECTRONICS_REFERENCE.step
```

넣을 위치: `lower_adapter/local_cad/reference/`

---

## 폴더

```
lower_adapter/local_cad/
├── README.md                  이 문서
├── reference/                 동결 레퍼런스 STEP (읽기 전용)
│   └── STEP_EXPORT_REQUEST.md 필요한 내보내기 목록
├── build123d/
│   ├── parameters.py          W2 파라미터 + 동결 상수 + 허용 오차
│   ├── geometry_utils.py      STEP 임포트/출력, bbox/부피, 왕복 비교, STL 검사
│   ├── import_reference.py    레퍼런스 검사 + 무변경 왕복 (§9)
│   ├── ergo_shell.py          인체공학 외피 생성 (편집 대상)
│   ├── assembly_preview.py    조립 프리뷰 STEP (부품 분리 유지)
│   ├── verify_geometry.py     로컬 검증 (Onshape 미조회)
│   └── smoke_test.py          엔진 스모크 테스트
├── export/
│   ├── step/                  설계 마스터
│   ├── stl/                   슬라이싱용
│   └── brep/
├── preview/
└── reports/                   smoke_test.json / reference_inspect.json 등
```

`ergo_shell.py` · `assembly_preview.py` · `verify_geometry.py` 는 레퍼런스가 없으면
**형상을 만들지 않고 필요한 파일을 알려주고 종료**한다.

---

## Python 환경

전역 Python 을 건드리지 않고 **격리 venv** 를 쓴다.

```
시스템 Python   3.12.6   C:\Users\User\AppData\Local\Programs\Python\Python312
격리 환경       .venv-build123d/         (저장소 루트, 약 592 MB)
  python        3.12.13
  build123d     0.11.1
  cadquery-ocp-novtk 7.9.3.1.1
  ocpsvg        0.6.0
  numpy 2.5.2 / scipy 1.18.0
FreeCAD CLI     미설치 (선택. 시각 확인 용도로만 쓸 수 있다)
```

만들 때 쓴 명령:

```bash
python -m venv .venv-build123d
.venv-build123d/Scripts/python -m pip install --upgrade pip
.venv-build123d/Scripts/python -m pip install build123d
```

이후 **모든** 로컬 CAD 명령은 이 인터프리터로 실행한다:

```bash
.venv-build123d/Scripts/python lower_adapter/local_cad/build123d/<script>.py
```

> `.venv-cadquery/` 는 엔진 전환 전에 만들다 만 것이다. **사용하지 않는다.**
> 지우는 데 시간을 쓰지 않았을 뿐이다.

> Windows 설치 주의: pip 를 동시에 두 번 돌리면 `WinError 32/5` 로 깨진다
> (`ipython.exe`, `scipy/_fblas.pyd` 등이 잠긴다). 한 번만 순차 실행할 것.

---

## 동결 대상 (편집 금지)

```
CUSTOM_GIMBAL = NOT ALLOWED
STOCK_GIMBAL  = REQUIRED
```

- 스톡 짐벌 내부 일체 (베어링 / Pitch / Roll / Spring_holder / 스프링 / 샤프트 /
  홀 / 마그넷 / 스톡 Base / OneGrip↔Pitch 인터페이스)
- 검증된 내부 공동 (conformal cavity), 캐리어 개구, 마운팅/인서트 형상
- `BOTTOM_CARRIER` 및 카트리지 마운팅
- 20° 인체공학 기준면, 그립 중립축 직교 관계, `HAND_REF` 위치

편집 대상은 **인체공학 외피 하나뿐**이다.

### 유지해야 할 검증값

```
경사 인체공학 기준면            20.000 deg
그립 중립축 ⟂ 기준면            90.000 deg
HAND_REF 변화                   0 mm
하우징 아래 스톡 돌출             0 mm
짐벌 모션                       ±10 deg (중립 / ±10 X / ±10 Y / 코너 4)
```

참고 (Onshape W2 결과 — 재구성 목표가 아니라 대조용):

```
외형        128.6 x 219.7 x 139.9 mm
손목 지지    7,173 mm2 @ 7.0 deg
```

### 좌표계 정책 (§7)

Part Studio STEP 각각의 로컬 좌표계를 **임의로 맞추지 않는다.**
`ONEGRIP_LOWER_ASSEMBLY_REFERENCE.step` 을 world transform 기준으로 삼고,
개별 STEP 의 위치는 어셈블리와 비교해 **실제 rigid transform 을 계산**한다.
근사 좌표를 직접 입력하지 않는다.

> 어셈블리는 **편향 상태**로 저장돼 있다 (Pitch 5.6062°, Roll 0.452°).
> 중립 복원 행렬은 `lower_adapter/cad_dump/stock_frames.json` 에 있다.

---

## W2 인체공학 파라미터 (`build123d/parameters.py`)

```python
WRIST_PAD_ANGLE  = 7.0    # 평가 범위 5 / 7 / 9
WRIST_PAD_LENGTH = 85.0   # 평가 범위 70 / 85 / 100
WRIST_PAD_WIDTH  = 86.0
WRIST_PAD_RADIUS = 16.0
WRIST_ANCHOR_Y   = -20.0
EDGE_FILLET      = 3.0    # 실패 시 2.5 -> 2.0 (해당 group 만)
FRONT_RAKE       = 5.0
SHELL_WALL       = 5.0    # 일반 외피
WRIST_WALL       = 6.0    # 손목 접촉면
NECK_WALL        = 4.5    # 손목 넥 최소
```

이 값을 바꿔도 **내부 코어는 재구성되지 않는다.**

---

## 명령

```bash
# 엔진 스모크 테스트 (레퍼런스 없어도 실행 가능)
.venv-build123d/Scripts/python lower_adapter/local_cad/build123d/smoke_test.py

# 레퍼런스 검사 + 무변경 왕복
.venv-build123d/Scripts/python lower_adapter/local_cad/build123d/import_reference.py

# 외피 생성 / 프리뷰 / 검증  (레퍼런스 필요)
.venv-build123d/Scripts/python lower_adapter/local_cad/build123d/ergo_shell.py
.venv-build123d/Scripts/python lower_adapter/local_cad/build123d/assembly_preview.py
.venv-build123d/Scripts/python lower_adapter/local_cad/build123d/verify_geometry.py
```

Onshape 접속 없이 STEP/STL/BREP 가 처음부터 다시 만들어져야 한다.

## 출력

```
export/step/ERGO_HOUSING_W2.step        설계 마스터
export/step/ONEGRIP_LOCAL_PREVIEW.step  조립 프리뷰 (fuse 하지 않고 부품 분리 유지)
export/stl/ERGO_HOUSING_W2.stl          슬라이싱용
export/brep/ERGO_HOUSING_W2.brep
```

단위는 전부 **mm**. STEP 이 설계 마스터이고 STL 은 파생물이다.

## 검증 허용 오차

```
20.000 / 90.000 판정       1e-4 deg
좌표 일치                  1e-3 mm
STEP 왕복 bbox             1e-6 mm
STEP 왕복 부피 상대오차      1e-6
```

## 알려진 제약

- **캐시는 정밀 CAD source 로 사용 금지.**
  `stock_full.npz` / `conformal_meshes.npz` / `ergo_meshes.npz` 는
  chordTolerance 0.0002~0.0003 의 근사 삼각형망이다.
  시각 대조 · 충돌 교차검사 · 회귀 비교에만 쓴다.
- OCC 필렛은 얇은 벽 근처에서 실패한다. 전역 반경을 밀어붙이지 말고 실패한
  edge group 만 반경을 낮추고 기록한다 (§16). 성공한 다른 필렛은 유지한다.
- 임포트한 STEP 이 중립 정지 상태 solid 뿐이라 관절 운동을 복원할 수 없으면,
  기존 검증된 모션 포락선(`lower_adapter/cad_dump/motion_configs.npz`)으로 검증한다.
  리포트에서 **DIRECT BREP COLLISION CHECK** 와 **CACHED MOTION ENVELOPE CHECK** 를
  반드시 구분해 적는다. 둘을 같은 수준의 검증으로 표현하지 않는다.
- build123d `Joint`(Rigid/Revolute/Ball)는 **스톡 운동 관계를 그대로 표현할 수 있을
  때만** 쓴다. 기능이 있다는 이유로 짐벌 운동학을 새로 설계하지 않는다.

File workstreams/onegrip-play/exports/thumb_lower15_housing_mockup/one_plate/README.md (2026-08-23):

# OneGrip lower-15 housing — two shells on one plate

Print file:

`OneGrip_lower15_housing_two_shells_one_plate.stl`

- unit: millimetre
- disconnected watertight components: 2
- mating planes placed on Z=0
- model footprint: approximately `167.6 × 177.7 mm`
- recommended bed envelope including 5 mm outer margin: approximately
  `177.6 × 187.7 mm`
- model height: approximately `38.7 mm`
- conservative projected spacing between shells: at least `8 mm`
- target bed check: `220 × 220 mm = PASS`

Import the STL as one file and keep both disconnected components. Disable
automatic part rearrangement if the slicer should preserve this verified
spacing. Scaling must remain at 100% in millimetres.

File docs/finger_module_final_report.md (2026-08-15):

# OneGrip Play 3방향 손가락 모듈 — 최종 구현 보고

작성일: 2026-08-13  
상태: CAD·디지털 검증 완료, P0 실물 검증 대기

## A. 결론

V1 손가락 입력 기구로 **Variant B — 독립 3패들 카트리지**를 선정했다.

- LEFT와 RIGHT는 Ø2mm 스테인리스 축을 쓰는 별도 회전 패들이다.
- CENTER는 회전하지 않는 2점 가이드 직선키다.
- 방향별 Panasonic `EVQ-P0E07K` 스위치 하나가 신호를 검출한다.
- 회전 패들의 짧은 캠이 별도 수직 팔로워를 내려 스위치에는 축방향 힘만 준다.
- 0.62mm 기본 스톱은 실측 작동거리 뒤 0.10~0.12mm가 되도록 U-shim으로 보정한다.
- 검지·중지·약지·소지는 접촉 폭과 레버비가 서로 다른 네 프리셋이다.
- 각 모듈은 나사 체결 카트리지라 본체를 재출력하지 않고 교체할 수 있다.

자동 검증은 최종 재생성 산출물에 대해 솔리드 간섭·캠/팔로워 접촉·유지핀
행정·단자 relief·±8mm/±8° 마운트를 다시 실행한다. 합격 수치는
`reports/geometry_validation.md`의 최신 소스 해시를 기준으로 하며, 실제 손에서
편안하고 95% 정확하다는 뜻은 아니다.

## B. 왜 이 안을 선택했는가

| 안 | 가중점수 | 판단 |
|---|---:|---|
| A 직접 3스위치 | 76.2/100 | 일정 백업. 빠르지만 손가락 중앙 지지가 약함 |
| B 독립 3패들 | **85.6/100** | V1 우선. 방향 분리·손가락별 튜닝·수리성 우수 |
| C 공유 로커 | 61.4/100 | 제외. 동시입력·공차·피벗 마모 위험 |

공식 Lalboard는 공용 로커가 아니라 중앙 독립 직선키와 방향별 독립 회전키를
쓴다. OneGrip는 그 원리를 3입력만 남기고 광학센서·자석·PCB 없이 단순화했다.
소지는 레버비 1.65로 손끝 계산 작동력을 약 0.448N까지 낮췄다.

## C. 생성한 파일

- 파라메트릭 CAD: [`../cad/finger-input-v1/finger_module_common.py`](../cad/finger-input-v1/finger_module_common.py)
- 손가락 프리셋: `finger_module_index.py`, `middle.py`, `ring.py`, `pinky.py`
- A/B/C 소스와 출력: [`../cad/finger-input-v1/variants/`](../cad/finger-input-v1/variants/)
- 손가락별 개별 출력 부품 STL·STEP·3MF와 조립체 STEP·3MF: [`../cad/finger-input-v1/printable/`](../cad/finger-input-v1/printable/)
- P0 지그·공차 쿠폰: [`../cad/finger-input-v1/test_fixture/`](../cad/finger-input-v1/test_fixture/)
- 4손가락 배열·P1 rail STEP/3MF: [`../cad/finger-input-v1/integration/`](../cad/finger-input-v1/integration/)
- 30개 렌더·편집 가능 Blender 5 장면·시각화 전용 캐시: [`../cad/finger-input-v1/renders/`](../cad/finger-input-v1/renders/)
- 자동 검증기: [`../cad/finger-input-v1/validate_geometry.py`](../cad/finger-input-v1/validate_geometry.py)
- 검증 결과: [`../cad/finger-input-v1/reports/geometry_validation.md`](../cad/finger-input-v1/reports/geometry_validation.md)
- 제작 안내: [`../cad/finger-input-v1/README.md`](../cad/finger-input-v1/README.md)
- Lalboard 분석: [`lalboard_analysis.md`](lalboard_analysis.md)
- 구조 비교: [`finger_module_tradeoff.md`](finger_module_tradeoff.md)
- BOM: [`finger_module_bom.md`](finger_module_bom.md)
- 시험법: [`finger_module_test_protocol.md`](finger_module_test_protocol.md)

## D. 바로 출력할 파일

P0에서는 다음만 출력한다.

1. `test_fixture/petg_tolerance_coupon.stl`
2. `test_fixture/fixture_base.stl`
3. `test_fixture/fixture_carrier.stl`
4. `printable/index_cartridge.stl`
5. `printable/index_bottom_cover.stl`
6. `printable/index_left_key.stl`
7. `printable/index_left_follower.stl`
8. `printable/index_center_key.stl`
9. `printable/index_right_follower.stl`
10. `printable/index_right_key.stl`
11. `test_fixture/hard_stop_shim_0.1mm.*`, `hard_stop_shim_0.2mm.*`,
    `hard_stop_shim_0.3mm.*`
12. 필요 시 `index_left/center/right_tpu_pad.stl`

`index_assembly.step/.3mf`와 `fixture_with_middle_module.step/.3mf`는 독립
솔리드를 유지한 조립 확인 권위본이며 한 덩어리로 출력하지 않는다. 조립체 STL은
배포하지 않는다. `renders/geometry_cache/*_visualization_only.stl`은 Blender용
평탄화 캐시로, 인쇄·치수 검증·제작 전달에는 사용하지 않는다.

## E. 필요한 P0 부품

- EVQ-P0E07K 3개 + 예비·선별용 3개
- Ø2mm 스테인리스 봉 약 30mm
- Ø1mm 스테인리스 봉 약 10mm
- M2×5~6 바닥 커버 나사 4개와 M2 insert 4개
- M3×8~10 카트리지 체결 나사 2개와 너트/insert
- JST-SM 4P 수·암 pigtail 1세트
- 26~28AWG 4색 연선 약 0.3m
- 열수축튜브, PETG, 선택 TPU 95A
- 지그용 M4×35 볼트·와셔·손잡이너트 2세트

전체 4손가락 부품비 추정은 보유 필라멘트 사용 시 약 5.5만~8.8만원,
필라멘트와 부자재를 새로 사면 약 9만~14만원이다.

## F. 조립 순서

1. 공차 쿠폰으로 Ø2mm 축공과 움직임 간극을 고른다.
2. 셸·LEFT/CENTER/RIGHT 키와 LEFT/RIGHT 팔로워를 출력하고 축공만 손으로 정리한다.
3. CENTER 두 post를 guide에 넣고 Ø1mm anti-loss pin 두 개를 끼운다.
4. 수직 팔로워를 guide에 넣고 LEFT/RIGHT를 ear 사이에 둔 뒤 Ø2mm 축 두 개를 끼운다.
5. 셸 하부에 스위치 3개를 넣고 한쪽 단자를 공통 GND로 묶는다.
6. 나머지 단자를 L/C/R에 납땜하고 JST 4P로 뺀다.
7. wire channel과 rear exit에서 strain relief를 만든다.
8. 바닥 커버를 M2로 닫고 100회 수동 복귀·연속성 시험을 한다.
9. 지그에 장착하고 높이·깊이·각도를 맞춘다.

세부 조립·출력 조건은 CAD README가 기준이다.

## G. 아직 검증해야 하는 것

- PETG 출력 후 실제 축공·guide·switch pocket 간극
- center/side 실측 작동력과 hard-stop 뒤 실제 overtravel
- LEFT/CENTER/RIGHT 각 30회 정확도와 인접·중복 입력
- CENTER 4Hz, LEFT/RIGHT 3Hz 연타와 100% 복귀
- 약지·소지 finger-enslaving과 소지 피로
- 10N 정적 하중과 1,500회 P0 내구 뒤 균열·유격
- P1 네 손가락에서 손가락별 높이·깊이·±8° 각도
- M 그립에서 엄지·손바닥·배선·스트랩과의 간섭

자동 검증 범위와 실제 파일 수는 최종 보고서에 자동 기록된다. 핵심 범위는
개별 부품 STL/STEP/3MF 재열기와 형식 간 치수, 조립체 STEP/3MF 독립 솔리드,
4프리셋×4상태의 실제 B-rep 간섭,
캠·팔로워·switch contact, switch pocket·단자·cover, anti-loss pin 이동창,
wedge·mount·fixture·array/rail 체결 정렬이다.

## H. 다음 행동

1. 공차 쿠폰과 검지 B안 P0를 즉시 출력한다.
2. 출력과 동시에 같은 스위치 6개를 작동력별로 선별한다.
3. 90회 무작위 입력과 반복 시험을 기록한다.
4. B안이 Gate를 통과하면 소지 프리셋을 출력한다.
5. B안이 Gate를 통과하지 못하면 2026-08-16에 A안으로 전환한다.
6. B/A가 결정된 뒤에만 네 손가락 rail을 출력하고 P1을 진행한다.
7. P1 데이터가 나온 뒤 기존 M 그립의 사본에만 체결 rail과 배선 창을 넣는다.

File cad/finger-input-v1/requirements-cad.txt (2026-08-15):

# Parametric source and neutral CAD exports were generated and validated with:
cadquery==2.8.0

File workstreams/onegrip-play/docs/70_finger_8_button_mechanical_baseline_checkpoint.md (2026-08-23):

# 70 — Finger 8-button mechanical baseline checkpoint

## 1. Checkpoint status

이 문서는 docs/62~69 승인 결과를 하나의 **production-intent mechanical checkpoint**로 고정한다. 이번 단계에서 production geometry 수정은 없다.

- **FINGER 8-BUTTON MECHANICAL INTEGRATION = COMPLETE / HARD FROZEN**
- all 8 button mechanisms = **ACCEPT**
- carrier-to-carrier penetration = **0.000000000 mm³**
- I2/I3 ↔ I4 carrier clearance = **0.444805280 mm**
- ALL-8 FULL unintended penetration = **0.000000000 mm³**
- M4 T2 ↔ N3 T3 penetration = **0.000000000 mm³**
- serviceability = **PASS**
- exterior = **PRESERVED**
- actual Thumb joystick integration = **WAITING FOR SZH-EK056 REFERENCE / PHYSICAL MEASUREMENT**
- N1/N2 final wiring route = **WAITING FOR ACTUAL JOYSTICK ENVELOPE**

HW504-A/B는 `REFERENCE / PLACEHOLDER GEOMETRY`일 뿐이며 이 checkpoint의 production-hard datum이 아니다. HW504 관련 clearance는 Finger geometry 수정 근거로 사용하지 않는다.

## 2. Frozen eight-button list

| button | carrier/service group | mechanism result | terminal state |
|---|---|---|---|
| N1 | N1/N2 shared | ACCEPT / motion, hard stop, return, service PASS | T1/T2/T3/T4 unchanged; actual joystick fit provisional |
| N2 | N1/N2 shared | ACCEPT / short U-shaped rear cradle / motion PASS | T1/T3 active; T2/T4 unused trimmed |
| I2 | I2/I3 shared | ACCEPT / independent motion PASS | T1/T2/T3/T4 unchanged |
| I3 | I2/I3 shared | ACCEPT / independent motion PASS | T1/T2/T3/T4 unchanged |
| M4 | M4/N3 shared | ACCEPT / independent motion PASS | T2 unused, external trim; T1/T3/T4 active unchanged |
| N3 | M4/N3 shared | ACCEPT / independent motion PASS | T3 unused, external trim; T1/T2/T4 active unchanged |
| I4 | standalone | ACCEPT / motion PASS | T1/T2/T3/T4 unchanged |
| M3 | standalone | ACCEPT / motion PASS | T1/T2/T3/T4 unchanged |

Finger exterior center, cap exterior, cap orientation, travel axis, switch pose, direct actuation, guide, retention, rear reaction and hard-stop architecture는 전부 frozen이다.

## 3. Canonical carrier sources

아래 STEP이 이 checkpoint의 canonical carrier geometry다. 상위 단계의 이전 STEP은 설계 이력이며 현재 carrier source가 아니다.

| carrier | canonical STEP | SHA-256 | note |
|---|---|---|---|
| N1/N2 shared | `build123d_workbench/out/n1_production_intent_mechanism/N1_N2_SHARED_CARRIER_N1_LOCAL.step` | `2485e34f8716395459f1f7b10384fd73a33695472f9aae689cf321d583830756` | docs/62 N2 short-U cradle 위에 docs/63 N1 승인 영역을 통합한 최종본 |
| I2/I3 shared | `build123d_workbench/out/i2_i3_production_intent_mechanism/I2_I3_SHARED_CARRIER_PRODUCTION_INTENT_LOCAL.step` | `1aa49477668d26d0617814e89c6dc25eca0564b12f927d9481d93896513aa92b` | docs/64 승인본; 이후 형상 변경 없음 |
| M4/N3 shared | `build123d_workbench/out/m4_n3_production_intent_mechanism/M4_N3_SHARED_CARRIER_PRODUCTION_INTENT_LOCAL.step` | `246b309ac3550d4c0f9e82e77f298e884077ef83ed763c863658f3e589a9bca3` | docs/65 승인본; docs/69에서는 terminal leg만 별도 변경 |
| I4 standalone | `build123d_workbench/out/real_integration_conflict_resolution/I4_CARRIER_LOCAL_MANUFACTURING_RELIEF.step` | `90b0002f3c3d1bdd95fc157809891351ad8f9cd5bb8cdcdb9a260fa9c33dcfe7` | docs/66 carrier에 docs/68 I4-only 비기능 외곽 relief 적용 |
| M3 standalone | `build123d_workbench/out/i4_m3_production_intent_mechanisms/M3_CARRIER_PRODUCTION_INTENT_LOCAL.step` | `021363afb7b761456b436d6252d12a3d786003ea19bef6acb908651708d44786` | docs/66 승인본; 이후 형상 변경 없음 |

I2/I3/I4 carrier를 더 수정하지 않는다. M4/N3 carrier도 terminal 문제를 이유로 수정하지 않는다.

## 4. Approved mechanism and cap sources

| button | approval lineage | generator source | canonical cap STEP | cap SHA-256 |
|---|---|---|---|---|
| N2 | docs/60 architecture + docs/62 rear support | `build123d_workbench/n2_production_intent_mechanism.py`; `build123d_workbench/n2_rear_reaction_support_redesign.py` | `build123d_workbench/out/n2_production_intent_mechanism/N2_PRODUCTION_INTENT_CAP.step` | `7f88cf6abfb8bea9a792e81b1def3ffa4ee96e2259f628ecb18d20f76ca5238c` |
| N1 | docs/63 | `build123d_workbench/n1_production_intent_mechanism.py` | `build123d_workbench/out/n1_production_intent_mechanism/N1_PRODUCTION_INTENT_CAP_LOCAL.step` | `5f7574f90682f7e511067aaac1d514274bb75a0ffeaeaae7e8a45b3502e1d6a5` |
| I2 | docs/64 | `build123d_workbench/i2_i3_production_intent_mechanism.py` | `build123d_workbench/out/i2_i3_production_intent_mechanism/I2_PRODUCTION_INTENT_CAP_LOCAL.step` | `57f272b308af329655239f408c3d992f5c8f947476a4d794d93caab675bafbf9` |
| I3 | docs/64 | `build123d_workbench/i2_i3_production_intent_mechanism.py` | `build123d_workbench/out/i2_i3_production_intent_mechanism/I3_PRODUCTION_INTENT_CAP_LOCAL.step` | `8c478ffcdabb136400c12ff661c4fdc857de79d4849c678b3dd75c1a1f1abe38` |
| M4 | docs/65 + docs/69 terminal resolution | `build123d_workbench/m4_n3_production_intent_mechanism.py`; `build123d_workbench/m4_n3_terminal_redundancy_resolution.py` | `build123d_workbench/out/m4_n3_production_intent_mechanism/M4_PRODUCTION_INTENT_CAP_LOCAL.step` | `d5c7542eece5d83abebd282a211263584c11b422e58fbbc533eee062f786a9ff` |
| N3 | docs/65 + docs/69 terminal resolution | `build123d_workbench/m4_n3_production_intent_mechanism.py`; `build123d_workbench/m4_n3_terminal_redundancy_resolution.py` | `build123d_workbench/out/m4_n3_production_intent_mechanism/N3_PRODUCTION_INTENT_CAP_LOCAL.step` | `d64032eb88a596a7da234b08d0b89bba97b7d4fd8bec6b072b651bfb72b6a6ec` |
| I4 | docs/66 + docs/68 carrier relief | `build123d_workbench/i4_m3_production_intent_mechanisms.py`; `build123d_workbench/real_integration_conflict_resolution.py` | `build123d_workbench/out/i4_m3_production_intent_mechanisms/I4_CAP_PRODUCTION_INTENT_LOCAL.step` | `ed0ab57a4b7b22fef0e421a7dbd3c3efab182f38fd4fdfc79f668eb5bbec46c0` |
| M3 | docs/66 | `build123d_workbench/i4_m3_production_intent_mechanisms.py` | `build123d_workbench/out/i4_m3_production_intent_mechanisms/M3_CAP_PRODUCTION_INTENT_LOCAL.step` | `996e6338961ecbbfe33e743d6b619c29335b0351880daf0c9d04b4fd265614d4` |

### Generator source hash guard

| source | SHA-256 |
|---|---|
| `build123d_workbench/n2_production_intent_mechanism.py` | `4402848c98dd1883f50abe096eacbf76f023558e0d9e9c44bfa576a8e59f9038` |
| `build123d_workbench/n2_rear_reaction_support_redesign.py` | `09ae6ff17601f4e1257499d0ff0cbe4f692afc821beb35d2ff25ed5c17bc00fd` |
| `build123d_workbench/n1_production_intent_mechanism.py` | `815ceb40df97f177485474014edc866925cc9883ae72202deccb4c3bc383126b` |
| `build123d_workbench/i2_i3_production_intent_mechanism.py` | `d62577fd138f85efb9ca096999825c727979f91d9511d40fc16b62055fe96342` |
| `build123d_workbench/m4_n3_production_intent_mechanism.py` | `f583ccf6b5f488f458d2bda6da519bfdb1a0cefd3270116a8aaa7e3f8a820f2d` |
| `build123d_workbench/i4_m3_production_intent_mechanisms.py` | `c6bfd2509133d17a1380d576328128dec6b3ed077d81a14765a2ee1b4f9fbcd8` |
| `build123d_workbench/real_integration_conflict_resolution.py` | `295bb1f34b31ee33ea74c3f66ba43da18a73a4e5c7a66ffbb690f5ba44a1b8de` |
| `build123d_workbench/m4_n3_terminal_redundancy_resolution.py` | `819983f61c2205c47a7e6164c82b4668bdf27303147f39493357112caf4e1500` |

Source를 수정하거나 canonical STEP의 SHA-256가 달라지면 이 checkpoint를 자동 상속하지 않는다. 명시적 unfreeze와 해당 subsystem regression이 필요하다.

## 5. Terminal requirements

### N2

- electrical Node A = T1/T2, Node B = T3/T4
- T1/T3 = active
- T2/T4 = unused external trimmed terminals
- plastic housing/internal leadframe 수정 금지
- 기존 physical sample에서 T2/T4 절단 후 T1↔T3 switching과 actuator return 정상 확인
- N1/N2 terminal-to-joystick clearance와 최종 solder/wire departure는 actual SZH-EK056 envelope까지 **PROVISIONAL**

### M4/N3 accepted trim overlay

Canonical terminal reference:

- `build123d_workbench/out/m4_n3_terminal_redundancy_resolution/M4_N3_TRIMMED_TERMINALS_LOCAL_REFERENCE.step`
- SHA-256: `2a97fdb65f5ccbf1483172bfcf97268bc618626b13bbd3de609e41c5e7b8417b`

| terminal | electrical role | selected external trim | remaining external stub | housing intrusion |
|---|---|---:|---:|---|
| M4 T2 | UNUSED / redundant Node A; T1 remains active | 1.758428 mm | 0.300 mm | NO |
| N3 T3 | UNUSED / redundant Node B; T4 remains active | 1.758428 mm | 0.300 mm | NO |

- old penetration = 0.283393028 mm³
- new penetration = 0.000000000 mm³
- conservative service-envelope clearance = 0.262733122 mm
- active terminal geometry change = 0
- active terminal solder access = PASS
- M4/N3 terminal geometry를 더 최적화하지 않는다.

N1, I2, I3, I4, M3의 terminal은 전부 원형 유지다. M4 T1/T3/T4와 N3 T1/T2/T4도 원형 유지다.

## 6. Physical-test conditional items

다음은 checkpoint를 무효화하는 CAD HOLD가 아니라 실물 production 검증 항목이다.

1. ITS-1105 continuity topology는 실물 sample에서 확인했다. 평상시 Node A(T1/T2)와 Node B(T3/T4)는 분리되고 누르면 연결된다.
2. N2 T2/T4 절단 후 switching/return은 sample test에서 확인했다. 다만 production 반복 절단 공정의 housing 보호, burr, 열손상 및 실제 SZH-EK056 인접 clearance는 실물 fixture에서 재확인한다.
3. M4 T2/N3 T3의 0.300 mm external stub는 CAD production-intent로 ACCEPT했다. 실제 절단 공차, burr/변형 및 housing 손상 여부는 첫 제작품에서 검사한다. 이는 현재 mechanical baseline의 HOLD가 아니다.
4. FDM 재료 수축, guide/bore 실제 fit, 0.350 mm travel 및 return-force 전달은 첫 통합 시제품에서 확인한다. CAD mechanism architecture는 재설계하지 않는다.
5. Wire OD 1.0~1.3 mm는 기존 공간 seed일 뿐 최종 AWG/피복 규격이 아니다.

## 7. Frozen dimensions and regression metrics

### Common mechanism dimensions

- cap tail = Ø4.5 mm
- guide bore = Ø4.8 mm
- nominal radial clearance = 0.15 mm
- shoulder = 6.5 mm square
- retention cavity = 6.8 mm square
- nominal lateral clearance = 0.15 mm
- central actuator contact = Ø3.0 mm
- nominal travel = 0.350 mm
- hard-stop residual REST/MID/FULL = 0.350 / 0.175 / 0.000 mm
- return = ITS internal return; separate spring 없음
- critical wall gate = ≥1.20 mm
- I4 relief 후 local wall = 1.280 mm; global critical wall = 1.200 mm

### Integration regression

| metric | frozen value | result |
|---|---:|---|
| carrier-to-carrier maximum penetration | 0.000000000 mm³ | PASS |
| I2/I3 ↔ I4 carrier clearance | 0.444805280 mm | PASS |
| I2/I3 combined FULL penetration | 0.000000000 mm³ | PASS |
| I2 ↔ I3 FULL cap gap | 2.141672 mm | PASS |
| M4 ↔ N3 minimum cap gap | 3.132654 mm | PASS |
| I3 REST ↔ I4 FULL cap clearance | 3.248773 mm | PASS |
| M4 ↔ M3 FULL cap clearance | 4.847042 mm | PASS |
| M4 T2 ↔ N3 T3 penetration after trim | 0.000000000 mm³ | PASS |
| ALL-8 FULL unintended penetration | 0.000000000 mm³ | PASS |
| serviceability | — | PASS |
| exterior geometry/centers/orientations | change 0 | PRESERVED |

docs/68 I4 relief와 docs/69 terminal trim은 material-removal-only 변경이며, 기존 ALL-8 motion envelope에 새 침투를 만들지 않는다. 두 단계의 local regression과 입력 hash guard도 PASS다.

## 8. Items waiting for actual SZH-EK056

현재 workspace에는 SZH-EK056의 controlled drawing, exact STEP 또는 실물 측정 registry가 없다. nominal 판매처 치수로 production geometry를 만들지 않는다.

필요한 controlled measurements:

1. PCB X/Y/Z
2. mounting-hole X/Y pitch와 hole diameter
3. PCB datum 기준 joystick center
4. X potentiometer envelope
5. Y potentiometer envelope
6. bottom push-switch envelope
7. shaft/pivot height와 center
8. connector/header envelope와 실제 사용 방향
9. joystick maximum moving envelope
10. solder joint, wire bend 및 connector mating/service envelope

측정 전 확정하지 않는 항목:

- actual joystick ↔ N1/N2 switch/body/terminal/carrier clearance
- Thumb support/mounting interface의 production fit
- N1/N2 final wire channel
- joystick maximum-motion envelope를 지나는 모든 local wire route
- global wiring trunk production geometry
- joystick 인접 fastening/MCU 배치

## 9. Next integration order

1. **SZH-EK056 실물 또는 신뢰 가능한 exact reference 확보**
2. 실물 측정 checklist를 controlled registry에 기록하고 실제 joystick local reference 생성
3. actual joystick ↔ frozen Thumb/N1/N2 local integration audit
4. joystick maximum moving envelope를 기준으로 N1/N2 final wiring route 확정
5. five service group의 global wiring trunk 검토
6. carrier fastening bosses와 shell reaction/load path 설계
7. MCU placement 및 connector/service clearance 설계
8. subsystem regressions 승인 후에만 full assembly production STEP / 필요한 shell boolean 검토
9. 최종 승인 이후 STL / print plate 생성

## 10. Explicitly deferred / forbidden at this gate

현재 생성하거나 수정하지 않는다.

- N1/N2 final wire channel
- global wiring trunk production geometry
- carrier fastening bosses
- MCU placement
- full assembly production STEP
- full shell boolean
- STL / print plate

**Production geometry edit = 0. Finger 8-button mechanical baseline checkpoint를 기록하고 STOP한다.**

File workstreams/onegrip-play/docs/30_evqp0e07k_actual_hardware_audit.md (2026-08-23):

# Panasonic EVQP0E07K actual-hardware physical-fit audit

- 감사일: 2026-08-20
- 실제 switch source of truth: **Panasonic EVQP0E07K**
- 동결 기준: **INDEX_FINAL_VALIDATED** (`03ede76e83b5c865d9a69c35`), `configuration=default`
- 실행 모드: **READ-ONLY / Onshape CAD WRITE 0건**
- 최종 판정: **INDEX AS-IS = FAIL / INDEX MODIFICATION REQUIRED = YES / MIDDLE CAD WRITE = HOLD**

## 0. 범위와 source integrity

이번 감사에서는 기존 `6 x 6 x 6 mm` OBB를 설계용 proxy로만 취급하고 실제 부품 판정에서
제외했다. 공식 source는 다음과 같다.

- [Panasonic EVQP0E07K 제품 페이지](https://industry.panasonic.com/ap/en/products/control/switch/light-touch/number/evqp0e07k)
- [Panasonic EVQP0 Over Travel 공식 도면/카탈로그, ANCTB36E 202507](https://mediap.industry.panasonic.eu/assets/imported/industrial.panasonic.com/ac/cdn/e/control/switch/light-touch/catalog/sw_lt_eng_over.pdf)
- 로컬 보존본: [`references/hardware/Panasonic_EVQP0_Over_Travel_ANCTB36E_202507.pdf`](../references/hardware/Panasonic_EVQP0_Over_Travel_ANCTB36E_202507.pdf)
- [Panasonic 공식 CAD 검색 결과](https://industry.panasonic.com/ap/en/downloads?part_no=EVQP0E07K&small_g_cd=203&tab=cad)

공식 CAD 검색에는 `evqp0-de-07k`, `3D CAD (STEP)`, 적용 부품 `EVQP0D07K / EVQP0E07K`가
존재한다. 그러나 다운로드가 이메일·성명·회사·전화번호·거주지와 개인정보 동의를 요구하므로
사용자 개인정보를 임의 입력하지 않았고 STEP은 내려받지 않았다. 따라서 이번 terminal 검사는
공식 2D 도면의 최대 envelope를 사용한다. 제3자 `PushBtn.SLDPRT`는 사용하지 않았다.

Panasonic은 구매 전에 최신 기술 사양을 확인하라고 도면에 명시한다. 아래 결과는 확보한
2025-07 공식 도면 기준이다.

## A. Official EVQP0E07K dimensions

| 항목 | 공식 값 | 이번 감사 적용 |
|---|---:|---:|
| body X/Y | `6.2 +/- 0.1 mm` | nominal 6.2 / maximum 6.3 |
| body height excluding push plate | `6.7 mm` | nominal 6.7 / conservative maximum 6.9 |
| free-position overall height | `Max. 7.45 mm` | maximum free height 7.45 |
| operating position | `7.0 +/- 0.2 mm` | 별도 stroke datum으로 유지 |
| actuator top | `diameter 3.0 mm`, side width 2.5 mm | nominal diameter 3.0 |
| general dimension tolerance | `+/- 0.2 mm` | 별도 공차 없는 6.7/3.0 치수에 보수 적용 |
| operating direction | top push | switch axis 방향 |
| operating force | max 0.74 N | force source of truth |
| operating life | 5,000,000 cycles | 참고 |

`6.9 mm` body height는 도면 하단의 general tolerance를 별도 공차가 붙지 않은 `6.7 mm`에
적용한 보수 envelope다. actuator projection은 독립 치수로 주어지지 않는다. nominal body top을
기준으로 한 파생 최대값은 `7.45 - 6.7 = 0.75 mm`이고, operating-position 파생 nominal은
`7.0 - 6.7 = 0.30 mm`다. 이 두 파생값을 독립 exact tolerance처럼 사용하지 않았다.

## B. Terminal dimensions

| 항목 | 공식 값 |
|---|---:|
| terminal 수 | 2, DIP / through-hole |
| terminal center pitch | `5.08 +/- 0.20 mm` |
| body mounting datum 아래 projection | `3.5 +/- 0.2 mm` |
| terminal section 1 | `0.8 +/- 0.1 mm` |
| terminal section 2 | `0.3 +/- 0.1 mm` |
| formed shoulder height | `1.8 mm` |
| formed offset | `0.75 mm` |
| body-side detail | `0.9 mm`, `Max. 0.3 mm` |
| reference PWB holes | `2 x diameter 1.00 +/- 0.05 mm` |
| reference PWB hole pitch | `5.0 +/- 0.1 mm` |

최악 envelope에는 pitch `5.28 mm`, section `0.9 x 0.4 mm`, projection `3.7 mm`를 썼다.
도면의 굽힘 형상을 직육면체 pin envelope로 보수 단순화했으며, STEP 없이 보이지 않는 내부
형상을 만들지 않았다.

## C. Actuator / travel

| 항목 | 공식 값 |
|---|---:|
| actuator | top push, nominal `diameter 3.0 mm` |
| pre-travel | max `0.5 mm` |
| movement differential | max `0.12 mm` |
| over-travel | min `0.2 mm` |
| returning force | min `0.1 N` |

현재 `4.5 mm` stem bore는 FeatureScript상 원형이 아니라 **4.5 x 4.5 mm square bore**다.
actuator가 bore와 동축이면 nominal lateral clearance는 `(4.5 - 3.0)/2 = 0.75 mm/side`,
actuator에 general `+0.2 mm`를 적용해도 `0.65 mm/side`다. 따라서 bore 자체는 PASS다.

그러나 현재 INDEX cap은 `7.6 x 7.6 x 4.0 mm` 단순 cuboid다. 각 cap volume도 정확히
`231.04 mm3 = 7.6 x 7.6 x 4.0`이고, 후면 stem/plunger가 없다. cap underside는 cap-normal
depth `2.6 mm`, holder front trim은 `2.8 mm`라 cap은 holder에 닿기 전 **0.2 mm**만 움직인다.

공식 최대 free height 7.45를 써서 actuator를 가능한 한 cap에 가깝게 놓아도 flat-cap underside와
actuator 사이 최소 간격은 다음과 같다.

| Button | cap normal - switch axis | 최소 free gap | holder stop 전 cap travel | first-contact shortfall | PT max까지 필요한 총 travel | OT min 포함 총 travel |
|---|---:|---:|---:|---:|---:|---:|
| I1 | 17.2059 deg | 1.7464 | 0.2000 | **1.5464** | 2.2698 | 2.4792 |
| I2 | 17.2059 deg | 1.7464 | 0.2000 | **1.5464** | 2.2698 | 2.4792 |
| I3 | 17.2059 deg | 1.7464 | 0.2000 | **1.5464** | 2.2698 | 2.4792 |
| I4 | 2.6572 deg | 1.9451 | 0.2000 | **1.7451** | 2.4456 | 2.6459 |

결론은 상시 과압이 아니라 **접촉 자체가 되지 않는 insufficient press**다. bore PASS가 cap/actuation
PASS를 의미하지 않는다. cap plunger와 hard stop을 실제 free/operating/over-travel에 맞춰 새로
정의해야 한다.

## D. Current 6.4 pocket nominal clearance

```
(6.4 - 6.2) / 2 = 0.10 mm/side
```

네 INDEX pocket 모두 nominal arithmetic fit은 성립한다. body front datum `5.3 mm`는 유지되고,
6.3 mm maximum body 기준 front-lip minimum도 I1/I2/I3/I4 각각
`1.0142 / 1.2430 / 1.2455 / 2.3100 mm`라 front seating lip은 남는다.

## E. Worst-case pocket clearance

```
(6.4 - 6.3) / 2 = 0.05 mm/side
```

P1S 공식 자료는 기본 nozzle이 0.4 mm임은 명시하지만 완성된 내부 pocket의 보편적 치수 공차를
보증하지 않는다. [Bambu Lab P1S 공식 사양](https://us.store.bambulab.com/collections/3d-printer/products/p1s)
상에도 특정 소재·방향·slicer 설정을 아우르는 hole/pocket tolerance가 없다. 따라서 0.05 mm/side를
`P1S에서 탈착 가능`으로 인증할 수 없다. 같은 소재·방향·설정의 6.4/6.5/6.6/6.7 gauge coupon과
실물 switch 측정 없이는 6.4를 service fit으로 승인하지 않는다.

| pocket | nominal per side | 6.3 body worst per side | frozen INDEX min divider | frozen INDEX min split-side wall |
|---:|---:|---:|---:|---:|
| 6.4 | 0.10 | **0.05** | 0.8000 | 1.4301 |
| 6.5 | 0.15 | 0.10 | 0.6628 | 1.3803 |
| 6.6 | 0.20 | 0.15 | 0.5255 | 1.3304 |
| 6.7 | 0.25 | **0.20** | 0.3883 | 1.2805 |

6.7은 `maximum body 6.3 + established service clearance 0.2/side`를 보존하는 치수지만, frozen
INDEX에 폭만 올리면 I1-I2/I2-I3 divider를 크게 훼손한다. 따라서 INDEX의 `6.4 -> 6.7` 단순
parameter bump는 금지다.

## F. INDEX I1 fit

- body/pocket: nominal 0.10, worst 0.05 mm/side; arithmetic fit, P1S service fit 미인증.
- front lip at 6.3 body: 1.0142 mm, PASS.
- nearest body SAT: I1-I2 nominal 1.0738, worst 0.9369 mm; 충돌은 아니나 기존 1.20 mm robustness gate FAIL.
- rear: body rear nominal/worst 12.0/12.2 mm, holder rear 12.5 mm; rear land 0.5/0.3 mm.
- retainer: 실제 body가 RWID pad와 충돌.
- terminal: 0..179 deg 도면-envelope sweep에서 collision-free rotation 0개; 최소 두 terminal prism이 RWID/JfD envelope와 충돌.
- cap: actuator first-contact shortfall 1.5464 mm; actuation FAIL.
- worst body-to-screw-B clearance: 6.6494 mm, PASS.

## G. INDEX I2 fit

- body/pocket: nominal 0.10, worst 0.05 mm/side; arithmetic fit, P1S service fit 미인증.
- front lip at 6.3 body: 1.2430 mm, PASS.
- I1/I3 양쪽이 지배 pair다: nominal minimum 1.0745 mm, worst 0.9372 mm; 충돌은 아니나 1.20 gate FAIL.
- retainer: 실제 body가 RWID pad와 충돌.
- terminal: 180개 회전 표본 모두 FAIL; 최소 두 terminal prism 충돌.
- cap: actuator first-contact shortfall 1.5464 mm; actuation FAIL.
- worst body-to-screw-B clearance: 5.0753 mm, PASS.

## H. INDEX I3 fit

- body/pocket: nominal 0.10, worst 0.05 mm/side; arithmetic fit, P1S service fit 미인증.
- front lip at 6.3 body: 1.2455 mm, PASS.
- I2-I3 nominal/worst SAT 1.0745/0.9372 mm; I3-I4는 3.6655/3.5467 mm.
- retainer: 실제 body가 RWID pad와 충돌.
- terminal: 180개 회전 표본 모두 FAIL; 최소 두 terminal prism 충돌.
- cap: actuator first-contact shortfall 1.5464 mm; actuation FAIL.
- worst body-to-screw-B clearance: 7.7531 mm, PASS.

## I. INDEX I4 fit

- body/pocket: nominal 0.10, worst 0.05 mm/side; arithmetic fit, P1S service fit 미인증.
- front lip at 6.3 body: 2.3100 mm, PASS.
- I3-I4 nominal/worst SAT 3.6655/3.5467 mm, body-neighbor PASS.
- retainer: 실제 body가 RZKD pad와 충돌.
- terminal: 180개 회전 표본 모두 FAIL; 어느 회전에서도 최소 한 terminal prism이 JaD/RWID/RZKD 중 하나와 충돌.
- cap: actuator first-contact shortfall 1.7451 mm; actuation FAIL.
- worst body-to-screw-B clearance: 5.3209 mm, PASS.

## J. Actual-SKU INDEX SAT

동일 center, 동일 F2 axes, 동일 full 15-axis OBB SAT를 썼다.

| envelope | I1-I2 | I2-I3 | I1-I3 | I3-I4 | minimum |
|---|---:|---:|---:|---:|---:|
| legacy 6 x 6 x 6 proxy | 1.3476 | 1.3490 | 4.6697 | 3.9314 | **1.3476** |
| EVQP nominal 6.2 x 6.2 x 6.7 | 1.0738 | 1.0745 | 3.9311 | 3.6655 | **1.0738** |
| conservative 6.3 x 6.3 x 6.9 | 0.9369 | 0.9372 | 3.6863 | 3.5467 | **0.9369** |

body-body collision은 없다. 하지만 nominal과 worst 모두 기존 `SAT >= 1.20 mm` robustness gate를
I1-I2/I2-I3에서 통과하지 못한다. 과거 1.3476 mm를 실제 SKU 값으로 재사용할 수 없다.

## K. INDEX retainer / preload impact

현재 공용 RWID와 I4 RZKD는 모두 proxy rear `11.3 mm`를 기준으로 pad front를
`11.3 - 0.15 = 11.15 mm`에 둔다.

| 항목 | nominal body | conservative max body |
|---|---:|---:|
| actual switch rear | 12.00 | 12.20 |
| holder rear | 12.50 | 12.50 |
| rear land | 0.50 | 0.30 |
| current pad front | 11.15 | 11.15 |
| current body-pad overlap | **0.85** | **1.05** |
| 0.15 preload용 pad front | 11.85 | 12.05 |

RWID는 I1/I2/I3 body와, RZKD는 I4 body와 실제 mesh-envelope 교차가 확인된다. retainer 나사를
정상 위치까지 체결할 수 없으므로 기존 preload/service PASS는 무효다. 6.7 nominal만 따라 pad
front를 0.70 mm rearward 이동하면 I4의 단순 축방향 disengagement 요구량은 기존 1.35에서
0.65 mm로 줄지만, body 높이 공차 0.4 mm peak-to-peak를 rigid pad 하나가 동시에 흡수하지 못한다.
compliant pad, spring, shim 또는 measured-select 조립 정의가 필요하다.

body 자체의 screw-B clearance는 worst에서도 최소 5.0753 mm라 screw B가 직접 병목은 아니다.
다만 pad/terminal relief가 바뀐 뒤 RWID service sweep과 RZKD service path를 다시 검증해야 한다.

## L. INDEX terminal / wiring impact

terminal rear tip datum은 다음과 같다.

```
nominal: 5.3 + 6.7 + 3.5 = 15.5 mm
worst:   5.3 + 6.9 + 3.7 = 15.9 mm
holder rear: 12.5 mm
projection beyond holder rear: 3.0 nominal / 3.4 worst
```

공용 slot은 depth 12.5..14.0 mm의 1.5 mm cut이고 한쪽 edge 방향이며, 실제 terminal은 worst
15.9 mm까지 간다. 두 terminal center는 worst `+/-2.64 mm`라 central 3.6 mm pad와 별개로
**두 pin 전용 통로**가 필요하다. I4 notch도 한쪽 edge-open 구조라 두 terminal을 모두 보장하지
않는다.

공식 최대 terminal envelope를 switch axis 주위로 1 deg 간격 180회 회전시켜 frozen
JaD/JfD/RWID/RZKD mesh와 검사했다. I1/I2/I3은 collision-free rotation 0, I4도 0이다. 따라서
terminal relief 없이 실제 부품을 삽입할 수 없다.

solder fillet, wire gauge, insulation OD, bend radius, strain relief는 Panasonic 부품 도면에 정의되지
않으며 wiring BOM도 아직 없다. terminal 자체가 이미 FAIL이므로 solder/wire는 추가 수치를
추측하지 않고 **NOT VERIFIED / HOLD**로 둔다.

## M. MIDDLE best row displacement

actual nominal `6.2 x 6.2 x 6.7`, pocket `6.7`, holder width `12.7`, front lip 2.3을 대상으로
기록된 bounded center/free-axis search에서 얻은 **best nominal certified candidate**는 다음이다.

```
row translation = (+1.25, +5.25, -7.45) mm
translation norm = 9.199320627 mm
maximum individual displacement = 12.486443 mm (M2)
nearest smaller tested failure norm = 9.094361 mm
holder rear nominal = 13.20 mm
holder rear for 6.9 worst body + 1.2 rear land = 13.40 mm
```

| Button | center X/Y/Z | optimized axis X/Y/Z |
|---|---|---|
| M1 | -19.761163 / +1.772271 / -13.450000 | -0.811000 / -0.551510 / -0.195233 |
| M2 | -13.352299 / -6.897458 / -16.250000 | -0.642550 / -0.752005 / -0.147033 |
| M3 | -3.824834 / -12.691743 / -13.450000 | +0.327648 / -0.702131 / -0.632186 |
| M4 | +7.371680 / -11.851408 / -13.450000 | +0.178538 / -0.811689 / -0.556134 |

최대 local-normal deviation은 26.5292 deg다. `best`는 기록된 bounded search의 최선이며 연속
전역최적 증명은 아니다.

## N. MIDDLE SAT

| 항목 | nominal 6.2 x 6.2 x 6.7 | same axes, worst 6.3 x 6.3 x 6.9 | gate |
|---|---:|---:|---:|
| minimum body SAT | **1.4261** | **1.3071** | >=1.20 PASS |
| minimum pocket divider | 0.8310 | 0.8310 | >=0.80 PASS |
| minimum split wall | 1.5215 | **1.4858** | >=1.50: worst FAIL |
| minimum actual front lip | 0.5132 | **0.4901** | >=0.50: worst FAIL |
| minimum screw clearance | 3.1243 | 3.0007 | >=2.50 PASS |

nominal geometry는 PASS다. 동일 axes에 conservative tolerance envelope를 적용하면 body SAT는
여전히 PASS지만 split wall과 front lip이 각각 0.0142/0.0099 mm 부족하다. worst envelope를
직접 넣은 추가 axis search에서도 norm 9.199/9.444/9.760 범위에서 compatible four-axis 조합을
인증하지 못했다. 이는 불가능 증명이 아니라 **tolerance-robust candidate 미확정**이다.

## O. MIDDLE - frozen INDEX clearance

nominal 후보의 exact triangle-to-OBB 결과:

- minimum holder-to-frozen-INDEX clearance: **0.853578 mm**, M4 holder vs frozen shell
- INDEX/RWID/RZKD intersection count: **0**
- conservative all-rotation terminal bundle vs frozen INDEX minimum: **4.915406 mm** (M3 vs RWID)
- neighboring terminal-bundle minimum SAT: **0.448911 mm**, collision 없음

따라서 MIDDLE의 terminal envelope가 frozen INDEX를 직접 침범하는 것이 현재 병목은 아니다.
하지만 MIDDLE 자체 holder rear land 12.2..13.4 mm에는 두 terminal pass-through가 필요하고,
worst terminal tip 15.9 mm 뒤쪽의 solder/wire bend 공간을 별도로 설계해야 한다.

## P. Recommended pocket width

**권장 기계 치수 기준은 6.7 x 6.7 mm**다.

근거는 `maximum body 6.3 + 2 x 0.20 service clearance = 6.7 mm`다. P1S의 실제 소재·방향·설정에
대해서는 반드시 coupon으로 확인한다. 6.6은 worst 0.15 mm/side, 6.5는 0.10, 6.4는 0.05다.

- MIDDLE: 6.7 pocket 기준 nominal optimized divider 0.8310 mm라 candidate가 성립한다.
- frozen INDEX: 6.7로 폭만 키우면 divider 0.3883 mm가 되어 허용할 수 없다.
- INDEX 대안: holder/axis 구조를 함께 재설계하거나, 6.4/6.5 coupon 결과에 따라 controlled
  post-process와 go/no-go gauge를 공정으로 정의한다. 무검증 6.4 direct print는 승인하지 않는다.

## Q. INDEX modification required YES / NO

### **YES**

그러나 범위는 `작은 pocket/retainer 수정`만이 아니다.

1. service-fit pocket 또는 제조 후가공 공정
2. 실제 6.7/6.9 body에 맞는 compliant rear retention
3. 두 DIP terminal용 통로와 solder/wire strain-relief 공간
4. 실제 actuator에 닿는 cap plunger와 free/PT/OT hard stops
5. actual-SKU I1-I2/I2-I3 robustness 재검증

현재 INDEX_FINAL_VALIDATED의 기능적 동결 상태를 깨지 않고는 EVQP0E07K를 정상 작동시킬 수 없다.
이번 감사에서는 그 어떤 CAD feature도 수정하지 않았다.

## R. MIDDLE modification strategy

1. EVQP0E07K를 유지한다. 현재 결과만으로 다른 switch 또는 low-profile 전용 SKU가 필요하다는
   근거는 없다.
2. 기본 pocket은 6.7, holder outer width는 12.7, worst-case rear datum은 최소 13.4에서 시작한다.
3. nominal candidate `(1.25, 5.25, -7.45)`를 seed로 쓰되 6.3 x 6.3 x 6.9 worst envelope에서
   split >=1.50, actual lip >=0.50을 동시에 만족하도록 center/axis를 다시 푼다.
4. terminal pair는 pitch 5.28 worst, section 0.9 x 0.4, depth 12.2..15.9를 keep-out으로 둔다.
   rear land에는 twin through-slots를 만들고 retainer는 terminal/solder 영역을 덮지 않게 한다.
5. cap은 flat cuboid를 복사하지 않고 actuator-axis contact plunger, PT 0.5 max, OT 0.2 min,
   body hard-stop을 함께 설계한다.
6. wire gauge, insulation OD, solder method, bend radius를 BOM에서 확정한 뒤 마지막 wiring sweep을 한다.

docs/29의 `low-profile 전용 SKU 불필요` 결론은 유지한다. 다만 6 x 6 x 6 proxy branch를 actual
EVQP0E07K CAD WRITE에 재사용하지 않는다.

## S. CAD WRITE GO / HOLD

### **CAD WRITE = HOLD**

HOLD 사유:

1. INDEX current 6.4 pocket은 worst 0.05 mm/side라 P1S removable fit 미인증.
2. actual body가 RWID/RZKD pad와 0.85 nominal / 1.05 worst 겹친다.
3. 실제 DIP terminals의 collision-free INDEX orientation이 없다.
4. flat INDEX caps는 actuator에 닿기 전에 holder front에 멈춘다.
5. actual INDEX SAT가 기존 1.20 robustness gate를 통과하지 못한다.
6. MIDDLE nominal candidate는 있으나 worst tolerance split/lip gate가 아직 미확정이다.
7. solder/wire envelope가 BOM에 없다.

## A-S decision summary

| Decision | 결과 |
|---|---|
| A. INDEX current geometry 그대로 사용 | **NO** |
| B. INDEX 수정 | **YES; pocket/retainer뿐 아니라 cap/terminal relief 필요** |
| C. MIDDLE EVQP0E07K 사용 | **nominal geometry 가능, tolerance-robust design 미확정** |
| D. MIDDLE 다른 switch 필요 | **NO — 현재 근거 없음** |
| INDEX modification required | **YES** |
| MIDDLE strategy | EVQP0E07K 유지 + worst-envelope 재최적화 + terminal/cap-aware architecture |
| CAD WRITE | **HOLD** |

## Reproducibility

- 계산 데이터: [`cad_dump/evqp0e07k_actual_hardware_audit.json`](../cad_dump/evqp0e07k_actual_hardware_audit.json)
- local GET-free 계산 스크립트: [`scripts/audit_evqp0e07k_hardware.py`](../scripts/audit_evqp0e07k_hardware.py)
- frozen inventory 근거: [`cad_dump/index_final_body_inventory_audit.json`](../cad_dump/index_final_body_inventory_audit.json)

스크립트는 로컬 tessellation과 수치 계산만 사용하며 HTTP client와 Onshape mutation path가 없다.

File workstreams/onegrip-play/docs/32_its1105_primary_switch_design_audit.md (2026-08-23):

# 32. ITS-1105-6mm primary finger-switch design audit

- 일자: 2026-08-20
- project primary switch: **ITS-1105-6mm**
- purchased quantity: **20**
- frozen CAD: `INDEX_FINAL_VALIDATED` / `03ede76e83b5c865d9a69c35`
- configuration: `default` frozen cache
- 실행: **READ-ONLY / Onshape CAD WRITE 0 / MIDDLE geometry 생성 0**
- 결론: **INDEX GRADE 1 / CASE B / NEXT CAD WRITE HOLD**

사용자가 제공한 ITS-1105 계열 drawing의 `L=6.0` variant를 mechanical reference로 사용했다. 판매처
nominal보다 실제 보유 lot 캘리퍼 측정값이 최종 CAD parameter에서 우선한다. 이번 계산은 drawing-derived
값과 physical-lot pending 값을 섞지 않았다.

이 문서는 `docs/31`의 Grade 2를 **Grade 1로 정정·후속 대체**한다. `docs/31`은 own-holder relief와
moving pad extension만 평가했지만, 이번에는 네 버튼 channel roll을 동시에 풀고 retainer와 함께 움직이지
않는 separate shim을 평가했다. 그 결과 center/axis/seat architecture를 바꾸지 않고 1.50 mm web을
보존하는 coordinated local-channel 해가 확인됐다.

---

## A. ITS-1105-6mm source-of-truth geometry

| 구역 | drawing-derived nominal |
|---|---:|
| body footprint | 6.0 × 6.0 mm |
| housing/lower-base envelope | 3.6 mm |
| overall `L` | 6.0 mm |
| actuator projection | 2.4 mm |
| actuator | Ø3.5 mm |
| travel | 0.25 ±0.10 mm |
| terminal | 4-pin THT |
| terminal pattern | 6.5 ±0.2 × 4.5 ±0.2 mm |
| terminal metal | 약 0.3 × 0.7 mm |
| body 후면 이후 terminal | 3.5 mm |
| no-bend fixed-root depth | 1.8 mm |
| terminal maximum outer width | 7.9 ±0.3 mm |

`L=6.0`은 actuator top에서 body rear까지의 전체 높이다. body/base의 세부 단차는 완전 치수화되지
않았으므로 6×6×3.6 housing envelope로 보수 처리했다. body 출구부터 1.8 mm factory-formed 구간은
FIXED ROOT, 나머지 약 1.7 mm는 BENDABLE DISTAL로 분리했다.

## B. drawing uncertainty

- 일반공차: ±0.3 mm, 별도 공차가 있는 6.5/4.5 pin pattern은 ±0.2 mm 우선
- drawing-worst body: 6.3×6.3×3.9 mm
- drawing-worst terminal outer width: 8.2 mm
- drawing-worst와 실제 보유 lot worst는 같지 않음
- bend radius가 없으므로 공식 최소값을 만들지 않고 prototype assumption으로 남김

`L`/housing-height 독립 stack은 cap free gap을 preload부터 미접촉까지 넓게 만들 수 있다. actual lot
측정 전에는 nominal만 보고 actuation PASS를 선언하지 않는다.

## C. 6×6×6 old proxy와 차이

| datum | old proxy | ITS nominal at current front seat |
|---|---:|---:|
| front/body datum | 5.3 | 5.3 |
| actuator free top | 없음 | 2.9 |
| rigid body rear | 11.3 | **8.9** |
| fixed root | 없음 | 8.9…10.7 |
| distal terminal tip | 없음 | 12.4 |

old proxy는 body rear를 2.4 mm 뒤에 놓고 actuator와 terminal을 생략했다. 따라서 같은 “6 mm”라는
표기만으로 rear pad와 cap을 재사용할 수 없다.

## D. current 6.4 pocket nominal fit

`(6.4 - 6.0) / 2 = 0.20 mm/side`. Nominal locating fit은 기하상 성립한다.

## E. drawing worst fit

body max 6.3을 적용하면 `(6.4 - 6.3) / 2 = 0.05 mm/side`다. P1S 0.4 mm nozzle 공정에서 removable
fit으로 인증된 값이 아니다. 6.4 / 6.5 / 6.6 / 6.7 coupon을 기록만 하며 이번에는 생성하지 않았다.

## F. INDEX nominal body SAT

| pair | SAT separation |
|---|---:|
| I1-I2 | 1.443121 |
| I2-I3 | 1.348986 |
| I1-I3 | 6.661942 |
| I3-I4 | 4.158761 |
| **minimum** | **1.348986 PASS** |

center와 F2 axis는 변경하지 않았다. nominal gate `≥1.20 mm`를 통과한다.

## G. INDEX worst body SAT

| pair | SAT separation |
|---|---:|
| I1-I2 | 1.023677 |
| I2-I3 | **0.937248** |
| I1-I3 | 6.176579 |
| I3-I4 | 3.830997 |

drawing-worst는 1.20 mm gate를 실패한다. 실제 lot body X/Y가 nominal 근처인지 측정하면 해소될 수
있는 항목이지만, 측정 전 tolerance를 무시해 PASS로 바꾸지 않는다.

## H. actuator / bore result

- Ø3.5 actuator vs Ø4.5 bore: nominal radial clearance **0.50 mm**
- Ø3.8 drawing-worst actuator: radial clearance **0.35 mm**
- bore와 actuator는 동일 F2 axis: coaxial passage PASS
- cap normal과 F2 axis 편차: I1/I2/I3 17.2059°, I4 2.6572°
- cap underside contact offset: I1/I2/I3 약 0.805 mm, I4 0.121 mm로 cap 면 안에 있음

## I. cap actuation result

현재 cap underside depth는 2.6 mm, holder first stop은 2.8 mm라 available stroke는 0.20 mm다.

| | nominal free gap | 0.15 actuation까지 | nominal 0.25 | max 0.35 | 현재 stop 대비 max 부족 |
|---|---:|---:|---:|---:|---:|
| I1 | 0.170219 | 0.313506 | 0.409031 | 0.504556 | 0.304556 |
| I2 | 0.170219 | 0.313506 | 0.409030 | 0.504555 | 0.304555 |
| I3 | 0.170218 | 0.313505 | 0.409030 | 0.504555 | 0.304555 |
| I4 | 0.296882 | 0.446721 | 0.546613 | 0.646506 | 0.446506 |

현재 cap은 actuator가 최소 travel에 도달하기 전에 holder에 닿는다. Grade-1 후보는 actual measured free
gap을 닫는 `cap underside contact boss`와 local stop recess다. free gap을 0으로 가정한 이론적 recess
하한은 I1-I3 약 0.134 mm, I4 약 0.150 mm지만, 실제 설계값은 의도한 free clearance를 더해 정한다.

## J. I1 rear pad result

- ITS rear: 8.9 mm nominal
- RWID pad front: 11.15 mm
- gap: **2.25 mm**, contact 없음

## K. I2 rear pad result

- ITS rear: 8.9 mm nominal
- RWID pad front: 11.15 mm
- gap: **2.25 mm**, contact 없음

## L. I3 rear pad result

- ITS rear: 8.9 mm nominal
- RWID pad front: 11.15 mm
- gap: **2.25 mm**, contact 없음

## M. I4 rear pad result

- ITS rear: 8.9 mm nominal
- RZKD pad front: 11.15 mm
- gap: **2.25 mm**, contact 없음

moving pad를 8.75 mm까지 연장하면 shared service 요구가 2.07→4.84 mm, I4가 1.85→4.25 mm로
늘어나므로 최소안에서 제외했다. 우선안은 **retainer와 함께 움직이지 않는 중앙 rear spacer/shim**이다.

- nominal spacer length: 2.4 mm
- drawing-stack parameter range: 2.1…2.7 mm
- central contact candidate: Ø3.6 mm
- body rear 8.9 + spacer 2.4 = legacy contact rear 11.3
- current pad front 11.15와 nominal 0.15 preload 관계를 복원
- RWID/RZKD pad와 기존 service path는 변경하지 않음

shim은 retainer 제거 후 따로 빠지는 service part로 설계해야 하며 actual rear 측정 뒤 길이를 확정한다.

## N. I1 fixed-root rotation

- current holder, 0…360°: **clear range 없음 / 0개**
- terminal channel nominal seed: 174° 또는 354°
- drawing-worst robust seed: **170° 또는 350°**

## O. I2 fixed-root rotation

- current holder, 0…360°: **clear range 없음 / 0개**
- terminal channel nominal seed: 178° 또는 358°
- drawing-worst robust seed: **0° 또는 180°**

## P. I3 fixed-root rotation

- current holder, 0…360°: **clear range 없음 / 0개**
- terminal channel nominal/worst seed: **92° 또는 272°**

## Q. I4 fixed-root rotation

- current holder, 0…360°: **clear range 없음 / 0개**
- terminal channel nominal seed: 84° 또는 264°
- drawing-worst robust seed: **80° 또는 260°**

4-pin pattern은 180° 회전 대칭이므로 exact 0…179° 결과를 180…359°에 대칭 확장했다. current clear
range가 없다는 결과는 1° 해상도 전수, coordinated channel seed는 2° bounded joint search다.

## R. terminal channel requirement

필요 channel architecture:

```text
6.4 locating seat
  -> body rear부터 factory fixed-root OBB만 통과하는 4개 local channel
  -> holder rear까지 edge-open/open-rear 연결
  -> 뒤쪽에서 distal terminal 1회 성형 및 wire exit
```

| gate | nominal optimized | drawing-worst optimized |
|---|---:|---:|
| governing channel/web lower bound | **1.994452** | **1.659048** |
| required web | 1.500 | 1.500 |
| conservative symmetric clearance/channel | 0.247226 | **0.079524** |
| result at zero/allowed clearance | PASS | PASS, 매우 경계 |

worst channel extra는 6.4 seat 밖으로 측당 0.90 mm다. optimized worst rolls는 I1 170°, I2 0°,
I3 92°, I4 80°다. 이 조합에서 outer/split web과 adjacent channel SAT lower bound를 동시에 평가했다.

channel은 body seat 앞쪽을 건드리지 않으므로 existing pocket divider 0.80 mm를 유지한다. rear channel
구간의 minimum web도 1.50 mm를 넘는다. 다만 worst에서 공정 clearance가 0.08 mm/channel뿐이므로,
실측 root envelope와 printed channel coupon 없이 CAD 값으로 freeze할 수 없다.

## S. bendable terminal routing

- fixed root: nominal depth 8.9…10.7 mm, bending 금지
- bend point: factory-formed 1.8 mm 뒤에서만 허용
- distal: 약 1.7 mm, pliers로 조립 전 1회 성형
- I1 exit: local -v / RWID slot
- I2 exit: local +v / RWID slot
- I3 exit: local -v / RWID slot
- I4 exit: local -v / RZKD notch
- bend radius: `PROTOTYPE ASSUMPTION`, 공식값 미선언

도면 회로는 1-2와 3-4가 각각 common이다. direct wiring은 서로 다른 common group에서 한 핀씩
선택한다. 유효 예는 1+3, 1+4, 2+3, 2+4이며 1+2 또는 3+4는 스위칭 pair가 아니다. 네 핀은 모두
유지하고 unused pin도 절연한다. 절단은 승인하지 않는다.

## T. recommended assembly / solder sequence

| option | 판정 |
|---|---|
| 1. switch 삽입 → bend → solder | 인두/pliers 접근과 root load 때문에 비권장 |
| 2. distal pre-form → wire pre-solder/절연 → switch 삽입 | **권장** |
| 3. switch 삽입 → retainer 전 solder | channel 완성 후 조건부 가능, 공통절차로는 비권장 |

권장 공통 순서:

1. 실제 switch continuity와 pin group 확인
2. jig로 distal terminal 한 번만 pre-form
3. 서로 다른 common group의 두 핀에 wire pre-solder
4. 각 joint 절연/heat-shrink, unused terminal 절연
5. wire부터 open channel/slot으로 통과
6. switch body를 6.4 locating seat에 삽입
7. measured rear spacer 삽입
8. RWID/RZKD 체결
9. free stroke와 electrical actuation 확인

wire gauge, insulation OD, solder fillet envelope는 아직 없어 최종 solder-access PASS는 physical prototype
pending이다.

## U. INDEX modification grade

### **GRADE 1 / CASE B**

coordinated channel 계산으로 center/axis/layout이나 holder seat 전체를 바꿀 필요가 없음이 확인됐다.
Grade-1 범위는 terminal channel, separate rear shim, cap underside boss/local stop relief, tiny wire relief다.

## V. INDEX minimum modification plan

1. I1/I2/I3/I4 centers, F2 axes, openings, 6.4 locating seat를 freeze
2. actual measured root profile + `c_channel` parameter로 four local terminal channels 생성
3. robust seed roll `170° / 0° / 92° / 80°`에서 B-rep web ≥1.50 재검증
4. actual body rear 기준 non-moving central shim 길이 parameter화
5. measured actuator free height 기준 cap boss와 max-travel stop relief parameter화
6. 기존 RWID/RZKD pad, fastening, service direction은 먼저 보존
7. wire/solder envelope와 실제 조립 순서를 prototype으로 검증

이번 audit에서는 이 형상을 생성하지 않았다.

## W. MIDDLE same-switch feasibility

**YES, nominal geometry feasible / drawing-worst reoptimization pending.** 별도 low-profile switch가 필요하다는
증거는 없다.

| gate | nominal 6.0×3.6 | drawing-worst 6.3×3.9 |
|---|---:|---:|
| body SAT | 1.506315 PASS | 1.152128 FAIL |
| divider | 1.034066 PASS | 0.981542 PASS |
| split wall | 1.513915 PASS | 1.513915 PASS |
| screw | 7.682136 PASS | 7.482957 PASS |
| actual front lip | 0.500000 PASS 경계 | 0.427368 FAIL |
| frozen INDEX clearance | 0.513070 PASS | 0.456588 FAIL |
| frozen INDEX intersection | 0 | 0 |

## X. MIDDLE candidate row / axis

```text
common row Δ = (+1.500, +3.125, -5.125) mm
norm         = 6.187184 mm
per button   = 6.333 / 9.849 / 6.706 / 7.236 mm
```

| | center XYZ | candidate axis |
|---|---|---|
| M1 | `(-19.835372,-0.614992,-11.125000)` | `(-0.837519,-0.499950,-0.220481)` |
| M2 | `(-12.899418,-8.744828,-14.125000)` | `(-0.601521,-0.782846,-0.159135)` |
| M3 | `(-3.537874,-14.413709,-11.125000)` | `(+0.320429,-0.733473,-0.599452)` |
| M4 | `(+7.444328,-13.569623,-11.125000)` | `(+0.224859,-0.772793,-0.593489)` |

이는 CAD 승인이나 ergonomic 승인값이 아니라 actual-ITS rerun seed다.

## Y. MIDDLE terminal feasibility

- future holder는 처음부터 fixed-root four-channel과 open rear solder cavity를 포함해야 함
- local 0° seed의 frozen INDEX/RWID/RZKD root collision: 0
- external clear rotations nominal: M1 180 / M2 150 / M3 180 / M4 180, 각 180
- drawing-worst: M1 180 / M2 110 / M3 180 / M4 180, 각 180
- root-pair SAT: nominal min 0.264974, worst min 0.128496 mm

terminal implementation은 조건부 가능하지만 worst pair gap이 작아 MIDDLE channel/roll은 새 holder와 함께
재최적화해야 한다.

## Z. INDEX + MIDDLE same SKU

### **YES - ITS-1105-6mm를 공통 primary로 유지**

INDEX는 Grade-1 local modification, MIDDLE은 nominal candidate와 terminal-aware 신규 holder로 진행할 수
있다. physical-lot 측정과 worst-envelope rerun 전 production approval은 아니다.

## AA. EVQP0E07K finger primary exclusion

```text
FINGER_BUTTON_PRIMARY = false
```

EVQP0E07K에 맞춰 INDEX geometry를 재설계하지 않는다. EVQ는 여분 또는 다른 입력부 후보로만 남긴다.

## AB. physical measurements required before WRITE

Registry 파일은 이번 실행에서 수정하지 않았으며 다음 plan만 확정한다.

```text
PART:   ITS-1105-6mm
ROLE:   INDEX + MIDDLE PRIMARY FINGER SWITCH
STATUS: SELECTED / PHYSICAL LOT MEASUREMENT PENDING
QTY:    20
```

`MEASURE-02` 추가 항목:

- body X / body Y
- housing height / overall L
- actuator diameter / actuator projection
- fixed-root 시작점·factory profile·최대 외폭
- pin spacing / pin width / pin thickness
- 선택 표본의 free-position과 실제 actuation stroke

각 치수는 최소 여러 개 표본의 min/nominal/max를 기록하고, channel과 shim/cap parameter를 그 값으로
override한다.

## AC. NEXT CAD WRITE

### **HOLD**

CASE B의 최소 수정 경로는 확정했지만 다음 조건이 남았다.

1. actual lot body/root/actuator measurement 없음
2. drawing-worst channel clearance allowance가 0.080 mm/channel로 경계
3. pocket coupon과 terminal-channel coupon 미실시
4. wire gauge/insulation/solder envelope 미정
5. MIDDLE drawing-worst SAT/front-lip/INDEX robust clearance 미통과
6. 사용자의 명시적 CAD WRITE 승인 전

INDEX_FINAL_VALIDATED는 계속 freeze한다.

---

## 재현 파일

- `cad_dump/its1105_primary_switch_design_audit.json`
- `cad_dump/stock_6x6x6_switch_actual_fit_audit.json`
- `scripts/audit_its1105_primary_switch.py`
- `scripts/audit_stock_6x6_switch.py`

모든 계산은 frozen local tessellation과 analytic OBB/SAT를 사용했다. Onshape mutation path는 없다.

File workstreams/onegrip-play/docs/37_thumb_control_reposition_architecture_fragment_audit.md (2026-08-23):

# THUMB / INDEX / MIDDLE ergonomic and fragment read-only audit

## 0. Scope and source

- CAD mutation: **0**. Feature 생성/수정/삭제/suppress와 version/workspace 변경을 하지 않았다.
- source Part Studio: `Joystick` / `425d9199b59cfb1efd9ddc35`
- source version: `ITS1105_SAME_SKU_8BTN_FINAL` / `e05a9ff0fa5a7bd51eb848a7`
- right-hand mirror version: `ITS1105_RIGHT_HAND_8BTN_FINAL` / `f24e655bc9b1b5dc97189a55`
- configuration: `default`
- 이번 GET에서 final version의 records는 `32 = 30 solid + 2 wire`로 재확인했다.
- Onshape가 이후 GET에 daily quota `429`와 약 8시간의 `Retry-After`를 반환했다. immutable version의 기존 final audit와 Onshape에서 이미 export한 right-hand final 30-part STL을 사용했다. 오른손판은 `X -> -X`만 적용하므로 volume, connected-component, thickness, pure-Z clearance 판정은 좌측 source와 동일하다.
- ergonomic reach는 CAD에 anthropometric hand model이 없으므로 **visible control-center distance와 control/holder envelope clearance를 reach proxy**로 사용했다. 최종 인체공학 확정은 hand mock-up 또는 physical grip test가 필요하다.

## 1. Current thumb ↔ INDEX/MIDDLE relation

Thumb rigid cluster는 다음을 함께 이동하는 것으로 해석했다.

- `RYDD` Backplate
- original thumb caps 8개: `RAED/RAEH/RAEL/RBED/RBEH/RBEL/RDED/RDEH`
- `RHED` Small_joystick_attachment
- assembly의 HW504 thumb joystick 두 solid occurrence(`JFH`, `JFD`; 서로 겹친 별도 조이스틱 2개가 아니라 동일 module의 두 solid)

현재 가장 가까운 thumb control center는 `Button_corner_2 ↔ I1/M1`이다.

| metric | INDEX | MIDDLE |
|---|---:|---:|
| nearest control-center distance | 37.868 mm | 52.275 mm |
| four finger centers의 nearest-thumb 평균 | 41.654 mm | 53.706 mm |
| actual thumb geometry ↔ finger cap envelope | 21.535 mm | 35.870 mm |
| Backplate ↔ conservative holder envelope | 14.632 mm | 27.770 mm |

MIDDLE가 INDEX보다 thumb cluster에서 약 12–15 mm 더 멀다. 따라서 사용자가 본 “엄지와 finger controls가 멀다”는 인상은 CAD 좌표에서도 확인된다.

## 2. Pure -Z candidate comparison

Center distance는 external reach proxy이며, holder gap은 Backplate와 conservative integrated-holder envelope 사이의 최소 Euclidean clearance다. HW504 gap은 실제 assembly transform을 적용한 module AABB로 계산한 보수값이다.

| ΔZ | nearest center: INDEX | nearest center: MIDDLE | mean: INDEX | mean: MIDDLE | Backplate→INDEX holder | Backplate→MIDDLE holder | HW504→INDEX holder | screw B gap | result |
|---:|---:|---:|---:|---:|---:|---:|---:|---:|---|
| 0 | 37.868 | 52.275 | 41.654 | 53.706 | 14.632 | 27.770 | 21.773 | 9.469 | current |
| -6 | 33.066 | 46.374 | 36.585 | 47.889 | 9.819 | 21.938 | 15.773 | 4.958 | best feasible seed |
| -10 | 30.104 | 42.455 | 33.290 | 44.038 | 6.961 | 18.059 | 11.773 | 1.951 | mechanically marginal |
| -14 | 27.407 | 38.553 | 29.943 | 40.216 | 4.311 | 14.247 | 7.773 | **-1.057** | FAIL: screw B collision |

All dimensions are mm. `screw B gap < 0` means volumetric cylinder/Backplate interference.

### Shell seating result

Pure -Z is not a valid direct Transform even at -6 mm. The shell widens and its local normal rotates below the current thumb panel. With the rigid cap pattern translated only in Z, the cap centers sit inward of the target outer shell:

| ΔZ | cap-center to target shell mismatch | intact-region normal change | required approximate +Y correction | additional observation |
|---:|---:|---:|---:|---:|
| -6 | 4.049…7.165 mm | about 15…16° on intact side samples | about +5.5 mm mean | side controls additionally need radial X accommodation of about 2.9…4.1 mm |
| -10 | 9.159…11.613 mm on resolved samples | about 24.6…25.1° | about +9 mm | both wide-control rays fall through existing opening/void regions |
| -14 | 11.743…16.971 mm | about 39.7…49.0° on side samples | about +10.5 mm | strong shell-width mismatch plus screw B collision |

Direct wall-ray values at some center/split locations were 0.0–0.9 mm or missing because the ray passes through an existing thumb/finger opening, not because that value is a valid printable wall. Adjacent intact target regions are nominally about 3.0 mm at -6 and -10. Therefore old openings must be closed and the new Backplate perimeter/interface must be regenerated before wall thickness can be certified.

## 3. Recommended translation

The recommended **design-study seed**, not an approved CAD Transform, is:

`ΔX = 0 mm, ΔY ≈ +5.5 mm, ΔZ = -6 mm`

Reasons:

1. It reduces the nearest INDEX/MIDDLE center distance by 4.80/5.90 mm and the row-average proxy by 5.07/5.82 mm.
2. It retains 9.819 mm to INDEX holder, 21.938 mm to MIDDLE holder, and a conservative 15.773 mm HW504-to-INDEX-holder gap.
3. Screw B retains 4.958 mm under pure -Z; the approximate +Y correction moves the Backplate away from screw B rather than toward it.
4. -10 mm buys only another 2.96/3.92 mm center improvement but reduces INDEX-holder and screw-B margins to 6.961/1.951 mm.
5. -14 mm is a hard FAIL at screw B and has the largest shell-normal/width mismatch.

The +Y value is only a first rigid-panel seating correction. Because the shell grows laterally at lower Z, a single XYZ translation cannot put every button directly on the existing shell. The Backplate must remain the common rigid datum and receive a redesigned shell flange/adapter around its perimeter.

## 4. Expected modification range if thumb movement is later approved

The move is not a one-feature Transform. A safe implementation would have to change together:

1. Backplate, eight caps, Small_joystick_attachment, HW504 mechanism and their assembly mates as one rigid cluster.
2. Eight old shell openings and the old joystick opening: close/rebuild them without leaving plug bodies or thin patches.
3. New common Backplate perimeter cut, positive-overlap mounting flange and local shell blends.
4. Backplate screw/mount datums. Screw B is fixed and becomes the governing obstacle as ΔZ increases.
5. Thumb wiring exit and strain-relief volume. The current model has no wire-gauge, insulation-OD or solder-fillet envelope, so wiring is not certified by the geometric gap alone.
6. Joystick shaft opening and mechanism service path. Internal HW504-to-Backplate relationships remain unchanged under rigid motion; only shell/holder/screw relationships change.
7. Final shell wall: require at least the existing nominal 3 mm away from openings, plus a separately declared minimum bridge/web gate around the new perimeter.
8. Assembly order: pre-wire thumb parts, insert rigid cluster, fasten Backplate, then install finger switches/spacers/retainers. The -6 seed preserves more tool and wire access than -10/-14.

## 5. INDEX vs MIDDLE architecture by row

`n0/n` below means visible cap/opening surface normal. `F2/a` means the physical switch/actuator axis.

| row | shell ownership | switch center mm | F2 / switch axis | roll | seat architecture | holder architecture | terminal channel | rear support | retainer concept | surrounding obstacles | reason for difference |
|---|---|---|---|---:|---|---|---|---|---|---|---|
| I1 | JfD | (-22.224, -17.494, 9.000) | (-0.847668, -0.506167, -0.158916) | 0° | 6.4 seat, switch front 5.3, rear seat 11.5; 8.0 opening stays on `n0` | 12.4 pre-union blank, F2 axis; separate front trim on `n0` | four rigid-root channels, 0.20 knee overlap; open rear | independent 2.4403 spacer | shared `RWID` for I1–I3 | I2, side wall, RWID ear/boss, screw B region | strong side angle requires F2-axis holder while visible opening stays on shell normal |
| I2 | JfD | (-15.970, -26.208, 9.000) | (-0.387542, -0.574231, -0.721158) | 0° | same 6.4/F2 seat; 8.0 `n0` opening | same 12.4 blank; neighbor seats pre-cleared | four channels; open rear | independent 2.4403 spacer | shared `RWID` | I1/I3 convergence, shared service relief and wiring slot | converging F2 axes make common retainer preferable to per-button hooks |
| I3 | JfD | (-5.496, -29.325, 9.000) | (-0.068454, -0.997610, 0.009410) | 90° | same | 12.4 blank, **split-clipped**, front trim on `n0` | four channels rotated 90°; open rear | independent 2.4403 spacer | shared `RWID` | X=0 split, I2, I4/RZKD, RWID service envelope | split ownership removes one side of generic holder material |
| I4 | JaD | (5.496, -29.325, 9.000) | (0.024161, -0.968017, -0.249718) | 90° | same | 12.4 blank, **split-clipped** | four channels rotated 90°; open rear | independent 2.4400 spacer | separate `RZKD` | split, I3, screw B, shared RWID exclusion zone | opposite shell and service path prohibit sharing I1–I3 retainer |
| M1 | JfD | (-19.835372, -0.614992, -11.125) | (-0.837519, -0.499950, -0.220481) | 90° | 6.4 axis seat, front 5.2796, rear 8.8396; 8.4 guided opening on surface normal | 10.0 support ring + two continuous side beams/hooks, shell-first union | four rigid-root channels with 0.20 knee overlap | integrated beams/hooks + independent 2.44 spacer | no separate retainer | M2, I1 envelope, side wall | lower-profile switch can use integrated snap support and shorter body depth |
| M2 | JfD | (-12.899418, -8.744828, -14.125) | (-0.601521, -0.782846, -0.159135) | 90° | same | standard ring/beams/hooks | four channels, roll 90° | integrated + 2.44 spacer | no separate retainer | M1/M3, I2; row low point Z=-14.125 | joint axis/center optimization uses a 3 mm local Z drop to keep body/web clearance |
| M3 | JfD | (-3.537874, -14.413709, -11.125) | (0.320429, -0.733473, -0.599452) | 0° | same | split-trimmed ring, asymmetric local `shellAnchor`, beams/hooks | four channels, roll 0° | integrated + 2.44 spacer | no separate retainer | split, M2/M4, INDEX/RWID keep-outs | positive shell anchor is required after split trim; generic symmetric ring would not own JfD robustly |
| M4 | JaD | (7.444328, -13.569623, -11.125) | (0.224859, -0.772793, -0.593489) | 0° | surface normal and switch axis coincide | split-trimmed ring with shifted negative-side rail/hook | four channels, roll 0° | integrated + 2.44 spacer | no separate retainer | split, M3, I4/RZKD, JaD wall | opposite-shell split and nearby INDEX geometry require asymmetric support placement |

## 6. Differences that must remain

These are acceptable internal differences:

- each row's physical switch axis and selected terminal roll;
- INDEX deeper 12.4 pre-union holder versus MIDDLE 10.0 ring/beam system;
- terminal exit direction and open-rear routing;
- INDEX shared/separate removable retainers versus MIDDLE integrated snap beams/hooks;
- I3/I4 and M3/M4 split-side trims;
- M3 shell anchor and M4 asymmetric rail/hook;
- independent rear spacer thickness and service access tied to actual local body depth.

Removing these differences merely for visual symmetry would regress proven body, divider, split-wall, screw or service clearances.

## 7. Differences that can and should be unified

The current external values are not the same product language:

| visible item | INDEX | MIDDLE | assessment |
|---|---:|---:|---|
| nominal visible cap width | 7.6 mm | 8.0 mm | unwanted 0.4 mm mismatch |
| shell opening | 8.0 mm | 8.4 mm | unwanted 0.4 mm mismatch |
| cap proud/exposure datum | about 1.4 mm | about 0.2 mm | unwanted 1.2 mm mismatch |
| adjacent center pitches | 10.726 / 10.928 / 10.992 mm | 11.100 / 11.348 / 11.015 mm | already visually compatible |
| nominal visible edge gaps | 3.126 / 3.328 / 3.392 mm | 3.100 / 3.348 / 3.015 mm | already compatible within 0.38 mm |
| rear retention | RWID/RZKD | integrated hooks | internal only; keep different |

Recommended common external language for the next controlled redesign:

1. Use one shared visible cap top profile, provisionally `7.6 × 7.6 mm` because it preserves the tighter INDEX divider. MIDDLE can shrink outward without reducing its 10.0 support ring.
2. Use one `8.0 × 8.0 mm` visible opening/reveal (`0.2 mm` per side to a 7.6 cap). Keep MIDDLE's internal stem bore and stop lugs hidden below that datum.
3. Set one visible exposure target, provisionally `1.0 ± 0.1 mm`; tune the hidden stem/stop lengths separately to preserve actuation travel.
4. Use the same corner/chamfer language and no arbitrary external positive boss. Any holder ring must remain below the shell outer surface.
5. Preserve the current near-11 mm pitch. Do not move centers merely to chase a perfectly straight world-Z row.
6. Fit both visible rows to perceptually parallel shell-projected curves. M2's 3 mm Z drop may remain internally, but the cap/stem can decouple the visible top datum from the switch axis if visual review still shows a dip.

## 8. Fragment / sliver / orphan-solid inventory

### Final printable-solid result

- source solids: **30**
- STL triangle components: **30**
- multi-component part files: **0**
- unexpected disconnected solids: **0**
- boundary-edge parts: **0**
- non-manifold-edge parts: **0**
- degenerate-triangle parts: **0**
- whole-part bbox minimum dimension below 0.3 mm: **0**
- leftover boolean-tool solids: **0**; every solid maps to a declared shell, Backplate, thumb cap, attachment, INDEX cap/retainer/spacer or MIDDLE cap/spacer role.

Therefore there is no suspect orphan geometry requiring a `partId / featureId / volume / bbox / connected target` defect row. The suspect table is empty.

### Small bodies that can look like fragments but are intentional

These eight 3.6 mm diameter rear spacers are intentionally independent service parts. They must **not** be unioned into a shell or retainer.

| partId | feature reference | volume from final STL | bbox min → max mm | intended target/interface |
|---|---|---:|---|---|
| RmND | INDEX I1 `its1105Index/SPACER` | 24.831 mm³ | [11.690,-14.562,8.631] → [15.669,-10.222,12.573] | I1 body rear ↔ RWID |
| RqND | INDEX I2 `its1105Index/SPACER` | 24.831 mm³ | [9.931,-22.594,14.143] → [14.196,-18.245,18.396] | I2 body rear ↔ RWID |
| RuND | INDEX I3 `its1105Index/SPACER` | 24.831 mm³ | [2.927,-20.611,7.094] → [6.685,-17.927,10.717] | I3 body rear ↔ RWID |
| RyND | INDEX I4 `its1105Index/SPACER` | 24.828 mm³ | [-7.081,-21.200,9.470] → [-3.424,-17.935,13.565] | I4 body rear ↔ RZKD |
| R4PD | `MmpBMYK4r3YQubx6n` | 24.828 mm³ | [9.405,2.245,-10.932] → [13.416,6.583,-6.882] | M1 body rear ↔ integrated hooks |
| RkRD | `Mg4CS9ouVxzcPvhDU` | 24.828 mm³ | [4.677,-2.945,-14.495] → [9.020,1.205,-10.553] | M2 body rear ↔ integrated hooks |
| RaTD | `M5mAoLzCamzWWTulC` | 24.828 mm³ | [4.665,-9.153,-7.267] → [8.857,-4.917,-2.923] | M3 body rear ↔ integrated hooks |
| RLVD | `MPFPMgIUS7WLdMWzv` | 24.828 mm³ | [-7.211,-7.881,-7.328] → [-3.154,-3.711,-2.982] | M4 body rear ↔ integrated hooks |

The immutable local cache did not retain the four generated INDEX tree feature IDs, so their exact IDs are not invented here; their creating FeatureScript stage and partIds are exact. They are not suspect geometry.

### Tessellation sliver sanity check

Fine STL triangulation contains 1,419 narrow facets with altitude below 0.01 mm, mainly on JaD/JfD, RWID and the guided MIDDLE caps. These are tessellation facets, not separate solids:

- every file is one closed component;
- all boundary/non-manifold/degenerate counts are zero;
- no part has a near-zero whole-body bbox dimension;
- JaD and JfD are each one manifold component, so no duplicate holder fragment is present.

The narrow facets therefore do not justify deleting CAD bodies. Raw tessellation shape must remain a sanity check, not a B-rep identity gate.

### Positive-union/tangent prevention already present

- INDEX holder blank overlaps its shell by `FUSE = 0.20 mm` before shell-first union.
- INDEX and MIDDLE rigid-root channel knees overlap by `0.20 mm`; no zero-length butt joint is used.
- MIDDLE ring, beams and hooks overlap volumetrically; M3 has a dedicated 1.6 × 1.6 mm shell anchor across depth 1.2…3.6 mm.
- Each side beam/hook cluster is unioned separately to the owning shell, preventing a disconnected tool from being hidden in a broad multi-body boolean.

These rules satisfy the requirement that face-only or edge-only contact is FAIL.

## 9. Fragment removal/prevention plan for future writes

1. Keep the current intended 30-solid manifest as an allow-list and fail any write that adds an unnamed solid.
2. After each thumb move sub-step, export individual solids and require one closed component per part, boundary/non-manifold/degenerate count zero.
3. Close old thumb openings by editing/rebuilding the owning shell volume; do not add separate patch plugs.
4. Union the new Backplate flange with at least 0.20 mm declared positive overlap, then verify actual B-rep body count remains unchanged.
5. Build left/right flange tools separately and union each only to its intended shell. Never use one broad boolean across both identities.
6. Delete/consume every temporary boolean tool inside its atomic feature; a tool body appearing in the parts list is immediate HOLD.
7. Keep eight spacers explicitly named and packaged; in print layouts, label them so they are not mistaken for scrap.
8. Add explicit wire/solder/heat-shrink envelopes before certifying the thumb/finger shared interior volume.

## 10. Final decision

- recommended thumb Z candidate: **-6 mm**
- recommended feasibility seed: **(ΔX, ΔY, ΔZ) = (0, +5.5, -6) mm**
- pure `(0,0,-6)` direct Transform: **FAIL / not seated to shell**
- -10 mm: **HOLD / marginal screw and shell interface**
- -14 mm: **FAIL / screw B collision**
- INDEX/MIDDLE internal architecture: **different by necessity**
- INDEX/MIDDLE external UX: **cap/opening/exposure unification required**
- unexpected fragment/sliver/orphan solid: **0**
- current final printable-solid integrity: **PASS**
- CAD WRITE recommendation: **HOLD**

HOLD is caused by the thumb shell/interface and missing explicit wiring envelope, not by fragment geometry. The next safe step is a non-production branch/mock-up of the Backplate interface around the `(0,+5.5,-6)` seed, followed by wall, screw, wiring and hand-fit gates before any approved final CAD write.

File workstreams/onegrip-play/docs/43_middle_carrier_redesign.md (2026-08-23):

# OneGrip Play — build123d-first MIDDLE carrier redesign

Date: 2026-08-21  
Scope: M1~M4 redesign / local build123d geometry / Onshape CAD WRITE 0  
Frozen reference: `FINGER_SIMPLIFIED_CARRIER_V1` / `f51e9d9a868db9ef0fcd4b06`

## Decision

- **build123d local geometry gates: PASS**
- **printability: PASS WITH LOCAL SUPPORT**
- **Onshape production implementation: HOLD**
- **Onshape CAD WRITE: 0**

HOLD is not caused by a failed new solid. The authenticated current Onshape
B-rep/feature tree could not be re-read: API returned HTTP 402 and the browser
session was at sign-in. The exact new shell opening/captive-carrier interface
therefore remains intentionally unwritten. Current JaD/JfD, INDEX, RWID/RZKD,
screw and THUMB geometry were not changed.

## Design result

The previous MIDDLE implementation was not repaired or copied. A new
parameterized OCC model was created in
`build123d_workbench/middle_redesign.py`.

- M1/M2/M3: one removable three-switch carrier, one exact solid
- M4: one independent carrier, one exact solid
- caps: four identical external-language parts
- independent MIDDLE service parts: 6
- tiny spacer/hook/rail/anchor parts: 0
- unexpected fragments/slivers/orphan solids: 0
- switch axes: coincident with each local shell normal
- external target: 7.6 mm cap / 8.0 mm opening / 1.0 mm exposure

The carrier uses a 1.6 mm front frame and corner columns, two broad rear
support bars, and an open rear wiring side. All four fixed terminal roots are
cut as conservative clearance volumes. Bendable distal pins and direct-solder
wires exit on the side opposite the backbone.

The cap is a single FDM part with a broad 3.8 mm contact, a 1.4 mm continuous
skirt and two 1.2 mm shell-captive tabs. It uses no stop lug, 0.7 mm hook or
0.8 mm rail. At the maximum 0.35 mm press probe, both skirt-to-housing and
tab-to-carrier axial clearance are 0.25 mm; tab-to-housing radial clearance is
0.51 mm.

## M1~M4 datums

All units are millimetres. `axis = shell normal`, so every mismatch is 0°.

| Unit | Center XYZ | Actuation axis / shell normal | Mismatch | Roll | Owner |
|---|---|---|---:|---:|---|
| M1 | (-20.441892, 4.808880, -11.125000) | (-0.992161, -0.028542, -0.121659) | 0.000° | 90° | JfD |
| M2 | (-17.213380, -7.084496, -11.125000) | (-0.716360, -0.528358, -0.455704) | 0.000° | 90° | JfD |
| M3 | (-6.893459, -13.725680, -11.125000) | (-0.224260, -0.771794, -0.595014) | 0.000° | 0° | JfD |
| M4 | (7.383061, -13.587450, -11.125000) | (0.224859, -0.772793, -0.593489) | 0.000° | 0° | JaD |

All four centers use `Z = -11.125`; the former M2-only 3 mm dogleg is removed.
Arc stations are `-32.0, -19.5, -7.0 | +7.5 mm`. M4 remains separated because
it belongs to JaD and retains a separate carrier.

Center displacement from the previous implementation:

| Unit | Displacement |
|---|---:|
| M1 | 5.4577 mm |
| M2 | 5.5106 mm |
| M3 | 3.4254 mm |
| M4 | 0.0638 mm |

## Numeric gates

| Gate | Required | Result | Status |
|---|---:|---:|---|
| minimum switch-switch SAT | ≥ 1.20 mm | 1.3891 mm | PASS |
| minimum divider | ≥ 0.80 mm | 1.1227 mm | PASS |
| M3 JfD split ownership | ≥ 1.50 mm | 1.5042 mm | PASS |
| M4 JaD split ownership | ≥ 1.50 mm | 1.9900 mm | PASS |
| minimum cap-to-cap gap | > 0 | 3.7843 mm | PASS |
| axis mismatch | ≤ 5° target | 0.000° | PASS |
| carrier wall | ≥ 1.20 / prefer 1.60 mm | 1.60 mm | PASS |
| cap retention minimum | ≥ 1.20 mm | 1.20 mm | PASS |
| pocket side clearance X/Y | parameterized | 0.11 / 0.14 mm | PASS |
| minimum INDEX holder clearance | no collision | 6.0249 mm | PASS |
| minimum INDEX switch clearance | no collision | 11.1648 mm | PASS |
| minimum screw clearance | ≥ 2.50 mm | 5.7379 mm | PASS |
| cached INDEX shell keepout | collision 0 | 0 / 2.1803 mm min | PASS |
| cached RWID | collision 0 | 0 / 0.9909 mm min | PASS |
| cached RZKD | collision 0 | 0 / 9.7169 mm min | PASS |
| frozen THUMB components | collision 0 | 0 | PASS |
| switch-carrier OCC intersection | 0 mm³ | 0 mm³ | PASS |
| rigid terminal-root intersection | 0 mm³ | 0 mm³ | PASS |
| sampled straight insertion interference | 0 mm³ | 0 mm³ | PASS |
| cap vs carrier/housing at 0.35 mm | 0 mm³ | 0 mm³ | PASS |
| printable part solid count | 1 each | 1 each | PASS |
| unexpected fragment count | 0 | 0 | PASS |

Adjacent switch SAT values are M1-M2 1.5645, M2-M3 1.3891 and M3-M4
3.6417 mm. Divider values are 1.2810, 1.1227 and 3.3942 mm.

## Exact part inventory

| Part | Solids | Volume | Faces | Print mesh components |
|---|---:|---:|---:|---:|
| M1-M3 shared carrier | 1 | 690.455 mm³ | 186 | 1 |
| M4 carrier | 1 | 177.034 mm³ | 53 | 1 |
| M1 cap | 1 | 214.849 mm³ | 30 | 1 |
| M2 cap | 1 | 214.849 mm³ | 30 | 1 |
| M3 cap | 1 | 214.849 mm³ | 30 | 1 |
| M4 cap | 1 | 214.849 mm³ | 30 | 1 |

Every carrier connection has positive volume. No tangent-only union, leftover
boolean tool body or disconnected rear stop remains.

## Printability

The six parts were automatically oriented independently, then placed on one
70.09 × 30.80 × 15.32 mm STL plate with a 5.0 mm XY gap. The plate contains
exactly six disconnected printable components, as intended.

| Part | Print size XYZ | Build-plate contact | Downward >45° area | Requirement |
|---|---|---:|---:|---|
| shared carrier | 27.82 × 16.15 × 15.32 mm | 35.23 mm² | 14.71% | local/tree support |
| M4 carrier | 11.67 × 10.21 × 7.55 mm | 51.20 mm² | 6.31% | small local support |
| each cap | about 7.6~7.9 × 9.6~9.7 × 5.25 mm | 57.76 mm² | 2.10% | normally support-free |

The shared carrier is not claimed to be completely support-free. Its supports
are confined to a separately printable/serviceable part rather than the shell
interior. Functional 6.4 mm pockets, rear stops and terminal channels must be
kept free of dense support; use painted local/tree support under the outer
backbone only.

Recommended sequence:

1. Print caps external face down.
2. Print M4 on the keyed-stop/backbone side.
3. Print the shared carrier in the generated print-ready orientation and paint
   local supports only under downward backbone spans.
4. Deburr the 6.4 mm pockets without widening their parameterized fit.

## Assembly sequence

1. Insert each cap from the shell interior and push its 7.6 mm pad through the
   future 8.0 mm opening.
2. Pre-form and optionally pre-solder the selected ITS-1105 distal leads.
3. Insert M1~M3 switches straight into the shared carrier until the broad rear
   stops; no separate spacer is installed.
4. Route wires through the open rear side opposite the backbone.
5. Mount/capture the carrier in JfD.
6. Repeat with the independent M4 carrier in JaD.
7. Close the existing shell and verify 0.25 mm actuation and return.

Steps 5~7 are local feasibility results, not a production shell sign-off. The
exact shell docking/captive interface must be cut against the restored current
Onshape B-rep before any write is authorized.

## Visual QC

- [Exterior perspective](../renders/middle_redesign_build123d/01_exterior_perspective.png)
- [INDEX/MIDDLE comparison](../renders/middle_redesign_build123d/02_index_middle_comparison.png)
- [Transparent shell/internal](../renders/middle_redesign_build123d/03_transparent_internal.png)
- [M1-M3 exploded](../renders/middle_redesign_build123d/04_m1_m3_shared_carrier_exploded.png)
- [M4 exploded](../renders/middle_redesign_build123d/05_m4_carrier_exploded.png)
- [Finger-facing](../renders/middle_redesign_build123d/06_finger_facing.png)

Visual conclusions:

- M2 no longer forms a separate dropped row.
- M3 has no half-ring, auxiliary anchor or external exception boss.
- all four MIDDLE user-facing pads use the same nominal size and exposure.
- no small orphan-like pieces are visible; each carrier and cap is one solid.
- the exterior view is an overlay on the frozen shell reference. It does not
  falsely claim that the new 8.0 mm openings have already been written.

## OLD vs NEW

| Item | OLD MIDDLE | NEW build123d design |
|---|---|---|
| service parts | 4 caps + 4 spacers = 8 | 4 caps + 2 carriers = 6 |
| retention | 0.7 mm hooks / 0.8 mm rails | 1.2 mm captive tabs / 1.6 mm carrier walls |
| spacer | one tiny part per switch | integrated rear stops; 0 spacers |
| cap stop | small stop lugs | none |
| M3 exception | half-ring + auxiliary anchor | none |
| row | M2 about 3 mm lower | common Z continuous row |
| axis mismatch | 20.94° / 21.83° / 24.71° / 0° | 0° / 0° / 0° / 0° |
| print strategy | shell-integrated difficult internal support | independent orientation and local support |
| assembly | four fiddly holder/spacer stacks | one three-switch subassembly + one M4 subassembly |
| serviceability | many tiny parts | six robust parts; M4 remains independently replaceable |
| external language | 8.0 cap / 8.4 opening / low exposure | 7.6 cap / 8.0 opening / 1.0 exposure |

## Files

- Parameterized source: `build123d_workbench/middle_redesign.py`
- Exact validation/export: `build123d_workbench/validate_middle_redesign.py`
- Render generator: `build123d_workbench/render_middle_redesign.py`
- Print orientation/plate: `build123d_workbench/prepare_middle_print_stl.py`
- Numeric audit: `build123d_workbench/out/middle_redesign/middle_redesign_validation.json`
- Print audit: `build123d_workbench/out/middle_redesign/middle_redesign_printability.json`
- Six-part print STL: `build123d_workbench/out/middle_redesign/MIDDLE_6_parts_one_plate_print_ready.stl`
- STEP assembly reference: `build123d_workbench/out/middle_redesign/MIDDLE_reference_with_ITS1105.step`

## HOLD details and next gate

**PROBLEM**  
Current Onshape B-rep/feature tree and the exact future shell docking interface
are not available in the authenticated read path.

**CAUSE**  
API HTTP 402 and browser sign-in state prevented the mandatory current-model
recheck. Cached meshes can certify collision envelopes but cannot authorize a
production FeatureScript/shell write.

**MINIMAL FIX**  
Restore an authenticated current-version read, or export JaD/JfD plus RWID and
RZKD as current STEP/Parasolid references. Re-run the same datums and carrier
against those exact B-reps.

**ALTERNATIVE**  
Import the user-exported current STEP references into build123d and finish the
keyed/captive shell interface there before reproducing it in Onshape.

**RECOMMENDATION**  
Keep **Onshape CAD WRITE = HOLD**. After the B-rep recheck passes, implement
atomic phases M1-M3 carrier → JfD openings/interface → cap actuation → M4
carrier → JaD opening/interface → full wiring/service audit. JaD/JfD target
identity must remain first in every positive union.

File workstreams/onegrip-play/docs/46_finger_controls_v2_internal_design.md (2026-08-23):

# OneGrip Play — Finger Controls V2 Internal Design

## 1. Result

The user-approved external eight-button layout from `docs/45` was treated as
immutable input. All geometry work was performed locally with build123d 0.11.1
and OCCT against the immutable AP242 clean-shell references.

```text
ONSHAPE API CALL = 0
ONSHAPE BROWSER AUTOMATION = 0
ONSHAPE CAD WRITE = 0

EXTERNAL LAYOUT = FROZEN / PRESERVED
8-SWITCH INTERNAL FIT = PASS
N2 SEAM = PASS
CARRIER ARCHITECTURE = PASS
WIRING = PASS
FDM PRINTABILITY = PASS
LOCAL FINGER V2 = PASS
```

The final physical set is `I2 I3 I4 M3 M4 N1 N2 N3`. `I1 M1 M2` remain
removed and were not recreated.

## 2. Immutable source and local source of truth

- clean JaD: `local_cad/reference/JAD_CLEAN_PRE_FINGER.step`
- clean JfD: `local_cad/reference/JFD_CLEAN_PRE_FINGER.step`
- original thumb: `local_cad/reference/THUMB_ORIGINAL_PRE_FINGER_REFERENCE.step`
- approved exterior transforms: `build123d_workbench/finger_layout_reset.py`
- new parametric mechanism: `build123d_workbench/finger_controls_v2.py`
- exact validation: `build123d_workbench/validate_finger_controls_v2.py`
- render-only consumer: `build123d_workbench/render_finger_controls_v2.py`

The clean STEP files were imported but never overwritten. Generated shell,
carrier, cap, print-plate and validation artifacts are isolated under
`build123d_workbench/out/finger_controls_v2/`.

## 3. Approved external layout preservation

All eight approved center coordinates were read directly from the marker source.
The final center delta is `0.000000 mm` for every button. Cap size remains
7.60 mm with 1.00 mm nominal exposure. Standard openings are 8.00 mm; N2 uses
an 8.40 mm seam-relieved opening while keeping the approved center unchanged.

The final-to-approved wireframe overlay is
`renders/finger_controls_v2/10_approved_overlay.png`.

## 4. Surface, axis and switch placement

`axis` is the common cap-travel and ITS actuator axis. Roll describes the ITS
housing frame relative to the exterior marker frame; the circular actuator lets
this internal roll change without changing the approved cap center.
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

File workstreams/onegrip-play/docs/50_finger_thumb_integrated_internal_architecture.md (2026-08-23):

# OneGrip Play — Finger + lowered Thumb 통합 내부구조 V3

## 1. 최종 결론

LOCAL build123d + OCCT에서 승인된 Finger 8-button 외부 배열과 lowered thumb
rigid cluster를 그대로 유지한 통합 내부구조를 실제 B-rep으로 작성하고 검증했다.

- `FINGER EXTERNAL LAYOUT = PRESERVED`
- `THUMB EXTERNAL LAYOUT = PRESERVED`
- `LOCAL INTEGRATED V3 = PASS`
- Onshape API/browser/CAD write: **0**
- production Finger V2 overwrite: **0**
- physical validation kit 변경: **0**

이번 PASS는 production freeze 또는 실물 출력 PASS가 아니다. 다음 단계는 Finger와
lowered Thumb를 함께 포함한 **통합 functional validation section**의 FDM 시험이다.

## 2. 작업 경계와 exact source

| 항목 | 결과 |
|---|---|
| geometry kernel | build123d + OCCT exact B-rep |
| source file | `build123d_workbench/finger_thumb_integrated_v3.py` |
| render file | `build123d_workbench/render_finger_thumb_integrated_v3.py` |
| validation | `build123d_workbench/out/finger_thumb_integrated_v3/finger_thumb_integrated_v3_validation.json` |
| JaD source | immutable `JAD_FINGER_V2.step` |
| JfD source | immutable `JFD_FINGER_V2.step` |
| thumb source | exact `THUMB_TARGET_EXACT_MODULE.step` |
| Onshape access | API 0 / browser 0 / write 0 |

Combined model에는 clean JaD/JfD, frozen Finger caps, ITS-1105 ×8, exact lowered
thumb module, carrier 6개, Finger/Thumb wiring envelope, split thumb seat, 신규 screw
3개와 boss 6개가 동시에 들어간다.
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

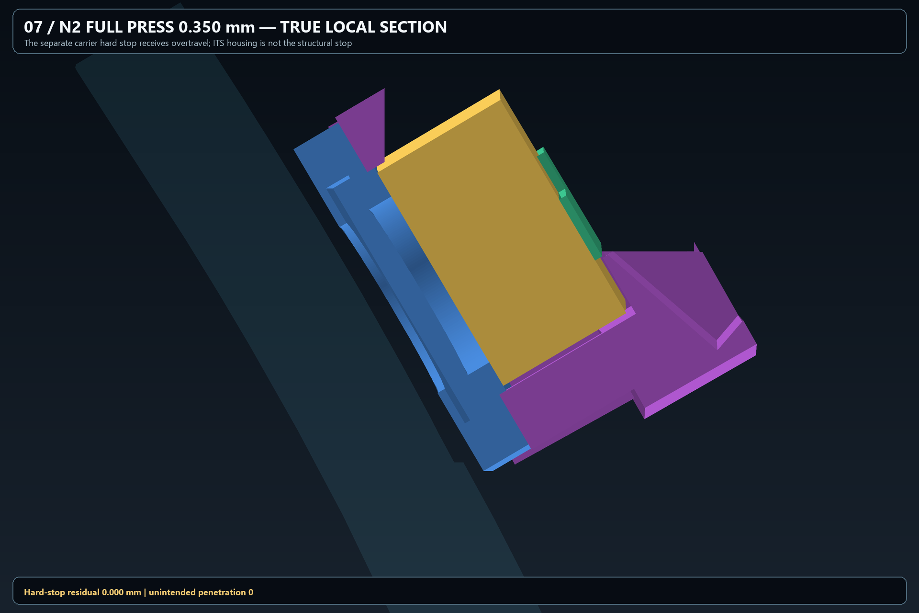
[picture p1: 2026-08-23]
workstreams/onegrip-play/renders/n2_rear_reaction_support_redesign/07_full_press_section.png

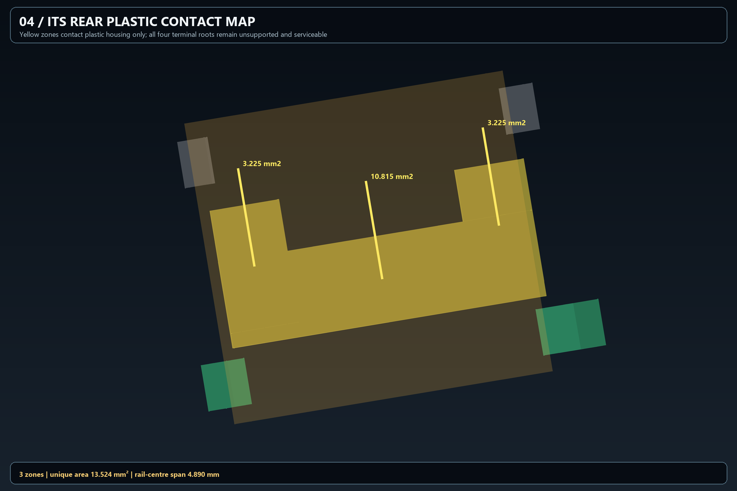
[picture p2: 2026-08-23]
workstreams/onegrip-play/renders/n2_rear_reaction_support_redesign/04_switch_rear_contact_map.png

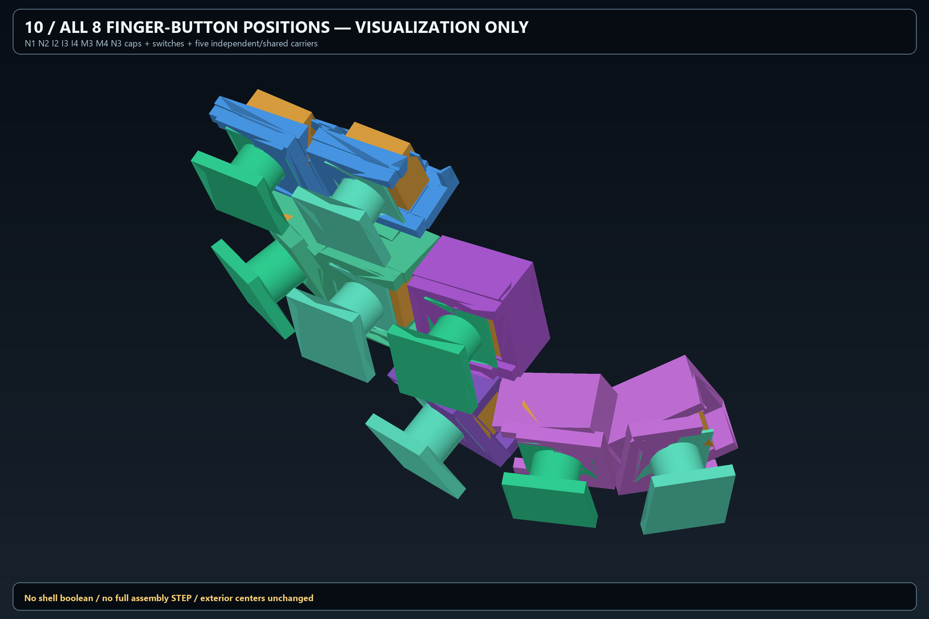
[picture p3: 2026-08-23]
workstreams/onegrip-play/renders/i4_m3_production_intent_mechanisms/10_all_8_button_overview.png

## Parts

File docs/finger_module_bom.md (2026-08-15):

# OneGrip Play 손가락 입력 모듈 스위치 선정 및 BOM

작성 기준일: 2026-08-13  
적용 범위: 검지·중지·약지·소지 4개 카트리지, LEFT/CENTER/RIGHT 각 1입력, 총 12입력  
제조 제한: 커스텀 PCB·만능기판 없음, FDM 부품과 직접 납땜 하네스 사용

## 1. 결론

V1 권장 스위치는 **Panasonic EVQ-P0E07K**다. 12개를 사용하고 고장·납땜 실수·선별 시험을 고려해 **15개 구매**를 권장한다.

선정 이유는 다음과 같다.

- 작동력 0.74 N으로 목표 범위 0.45~0.8 N 안에 들어온다.
- 6.2 × 6.2 mm, 스루홀 2단자라 PCB 없이 전선을 직접 납땜하기 쉽다.
- 프리트래블 0.5 mm 이하와 오버트래블 0.2 mm 이상을 제공해 FDM 공차를 조절식 하드스톱으로 흡수하기 쉽다.
- 기계 수명이 500만 회로 D2F-01F와 일반 6 mm B3F보다 길다.
- 공식 정격 범위가 **10 µA, 2 VDC부터** 시작하므로 3.3 V MCP23017 풀업 입력과 전기적으로 잘 맞는다.
- 국내 디바이스마트에서 낱개 주문이 가능하고 현재 표시 단가는 VAT 포함 638원, 10개 이상은 550원, 준비 기간은 4~5일이다.

근거: [Panasonic 공식 제품 사양](https://industry.panasonic.com/kr/ko/products/control/switch/light-touch/number/evqp0e07k), [Panasonic 공식 데이터시트](https://mediap.industry.panasonic.eu/assets/imported/industrial.panasonic.com/ac/cdn/e/control/switch/light-touch/catalog/sw_lt_eng_over.pdf), [디바이스마트 판매 페이지](https://www.devicemart.co.kr/goods/view?no=8921426)

> 주의: 스위치의 0.74 N은 스위치 플런저 위치의 힘이다. 키의 회전축과 접촉점 사이 레버비가 1:1이 아니면 실제 손끝 힘은 달라진다. CAD에서는 `F_finger ≈ F_switch × (pivot-to-switch / pivot-to-finger)`로 계산하고 P0 실측으로 확정한다.

## 2. 후보 비교

공식 데이터시트 수치와 국내 판매 정보를 분리해 정리했다. 가격·재고·납기는 변할 수 있다.

| 후보 | 형식 / 단자 | 공칭·최대 작동력 | 행정 특성 | 본체 크기 | 공식 수명 | 3.3 V 저전류 입력 적합성 | 국내 조달 | 판단 |
|---|---|---:|---|---|---:|---|---|---|
| **Panasonic EVQ-P0E07K** | SPST-NO, THT 2핀 | **0.74 N** | 프리트래블 ≤0.5 mm, 오버트래블 ≥0.2 mm | 6.2 × 6.2 × 7.45 mm | **500만 회** | **적합**: 10 µA/2 V부터 정격 | 디바이스마트 VAT 포함 638원, 10개+ 550원, 준비 4~5일 | **V1 최종 추천** |
| Omron D2FC-F-7N(20M) | SPST-NO, PC 핀 2개 + dummy | 0.59 ±0.15 N | PT 0.3 ±0.2 mm, OT ≥0.2 mm, MD ≤0.12 mm | 12.8 × 5.8 × 약 7.35 mm | **2,000만 회** | 조건부: 공식 최소 부하 1 mA/5 V라 MCP 내부 풀업만으로는 보증 범위 밖 | 디바이스마트 취급; element14 10개+ 약 1,264원, 포장·납기 확인 필요 | 수명·연타 최우수지만 전기 조건과 크기 때문에 2순위 |
| Omron D2F-01F | SPDT, PC 핀 3개 | **최대 0.74 N** | PT ≤0.5 mm, OT ≥0.25 mm, MD ≤0.12 mm | 12.8 × 5.8 × 6.5 mm | 100만 회 | 조건부: 공식 최소 부하 1 mA/5 V | 국내 정식수입 판매 약 990원, 당일배송 표시 | M2 체결홀이 장점인 P0 비교용 |
| Omron D2F-01F-D | SPDT, 납땜 러그 | 최대 0.74 N | D2F-01F와 동일 | 12.8 × 5.8 × 6.5 mm | 100만 회 | D2F-01F와 동일 | DigiKey KR 표시 재고 0, 단가 약 3,071원 | 직접 배선은 편하지만 조달성이 나빠 제외 |
| Omron B3F-1000 | SPST-NO, THT 4핀 | 0.98 ±0.29 N | PT 0.25 +0.20/-0.10 mm | 6 × 6 × 4.3 mm | 100만 회 | 적합: 공식 최소 부하 10 µA/1 V | 디바이스마트 VAT 포함 462원, 10개+ 330원, 준비 약 1주 | 저가 대안이나 특히 소지에는 너무 강함 |
| 무명 6 × 6 mm 택트 | 보통 THT 4핀 | 판매자별 상이 | 판매자별 상이 | 대체로 6 × 6 mm | 불명 | 불명 | 50~200원대가 흔하나 모델 추적 곤란 | 최종품 사용 금지, 형상 확인용만 허용 |

### 2.1 D2FC-F-7N(20M)

- 공식 사양: 0.59 ±0.15 N, PT 0.3 ±0.2 mm, OT 0.2 mm 이상, MD 0.12 mm 이하, 2,000만 회.
- 장점: 클릭이 빠르고 수명이 길어 반복 게임 입력 자체에는 가장 강하다.
- 단점: 12.8 mm 길이 때문에 3개를 한 손가락 폭 안에 직접 나란히 넣기 어렵다. 또한 공식 최소 적용 부하가 5 VDC 1 mA여서 MCP23017의 3.3 V 내부 풀업만 사용하는 회로는 제조사 보증 범위 밖이다.
- 사용하려면: 외부 풀업과 입력 전압 구조를 별도로 검토하고, 실제 접촉 신뢰성 시험을 해야 한다. V1 일정에서는 이 추가 위험을 받지 않는다.

근거: [Omron D2FC 공식 데이터시트](https://components.omron.com/system/files/2024-07/datasheet_pdf/B152-E1.pdf), [디바이스마트 판매 페이지](https://www.devicemart.co.kr/goods/view?no=15350143), [element14 Korea 판매 페이지](https://kr.element14.com/omron-electronic-components/d2fc-f-7n-20m-std/microswitch-spst-no-0-001a-6vdc/dp/4227184)

### 2.2 D2F-01F 및 D2F-01F-D

- 공식 사양: 핀 플런저 기준 최대 0.74 N, 릴리스 힘 최소 0.05 N, PT 0.5 mm 이하, OT 0.25 mm 이상, MD 0.12 mm 이하, 기계 수명 100만 회.
- 크기: 12.8 × 5.8 × 6.5 mm이며 6.5 mm 간격의 M2 체결홀 2개가 있어 FDM 고정은 가장 명확하다.
- D2F-01F는 PC 핀, D2F-01F-D는 소형 납땜 단자다. PCB 없이도 PC 핀에 직접 납땜할 수 있지만 `-D`가 배선 작업에는 더 적합하다.
- 접점은 미소부하용 금합금이지만 공식 최소 적용 부하는 5 VDC 1 mA다. MCP23017 3.3 V 내부 풀업만으로 쓰면 공식 보증 범위 밖이다.
- D2F-01F 표준형은 국내 조달이 쉽지만 `-D` 납땜형은 현재 재고와 가격이 불리하다.

근거: [Omron D2F 공식 데이터시트](https://omronfs.omron.com/en_US/ecb/products/pdf/en-d2f.pdf), [국내 정식수입 판매 페이지](https://buyomron.co.kr/), [D2F-01F-D DigiKey Korea](https://www.digikey.kr/ko/products/detail/omron-electronics-inc-emc-div/D2F-01F-D/368429)

### 2.3 Omron B3F-1000

- 공식 사양: 0.98 ±0.29 N, PT 0.25 +0.20/-0.10 mm, 100만 회, 6 × 6 × 4.3 mm.
- 공식 최소 적용 부하가 1 VDC 10 µA라 MCP23017 저전류 입력에는 적합하다.
- 가격이 낮고 흔하지만 목표 상한 0.8 N을 넘는다. 소지와 약지의 횡입력에는 피로와 연동 오입력을 증가시킬 가능성이 높다.
- P0에서 EVQ-P0E07K와 힘 비교를 위한 대조군으로 3개 정도만 사는 것은 유용하다.

근거: [Omron B3F 공식 데이터시트](https://components.omron.com/us-en/system/files/2023-01/datasheet_pdf/A070-E1.pdf), [디바이스마트 판매 페이지](https://www.devicemart.co.kr/goods/view?no=15958680)

## 3. 권장 스위치의 CAD 인터페이스

EVQ-P0E07K를 기본값으로 하되 다른 스위치를 시험할 수 있도록 다음 값을 파라미터화한다.

```text
SWITCH_MODEL              = "EVQ-P0E07K"
SWITCH_BODY_X             = 6.20 mm
SWITCH_BODY_Y             = 6.20 mm
SWITCH_BODY_H             = 6.70 mm   # 푸시판 제외 본체 기준
SWITCH_TOTAL_H            = 7.45 mm
SWITCH_FORCE_N            = 0.74 N
SWITCH_PRETRAVEL_MAX      = 0.50 mm
SWITCH_OVERTRAVEL_MIN     = 0.20 mm
SWITCH_TERMINAL_COUNT     = 2
SWITCH_TERMINAL_PITCH     = 5.08 mm
SWITCH_POCKET_CLEARANCE   = 0.20 mm/side  # P0 PETG 시작값
KEY_TO_PLUNGER_GAP        = 0.05~0.10 mm
STOP_AFTER_CLICK          = 0.10~0.15 mm  # 실제 샘플 클릭점 기준
```

권장 포켓 시작 치수는 6.6 × 6.6 mm다. 프린터별 수축과 elephant foot이 다르므로 6.4/6.6/6.8 mm 포켓 게이지를 먼저 출력한다. 스위치를 압입으로만 고정하지 말고, 탈착식 상부 클램프와 M2 나사 1개를 사용한다.

## 4. 하드스톱 필수 조건

스위치는 신호 검출만 담당하며 키의 구조 하중을 받지 않아야 한다.

1. 각 LEFT/CENTER/RIGHT 키에 **스위치와 독립된 PETG 쉘 스톱** 또는 M2 조절나사를 둔다.
2. 공칭 치수만으로 스톱 위치를 정하지 않는다. 실제 스위치의 클릭점까지 이동량을 측정한 뒤 스톱을 **클릭 후 0.10~0.15 mm**에 맞춘다.
3. EVQ-P0E07K의 공식 오버트래블 최소값은 0.2 mm지만, 이를 전부 구조 여유로 소비하지 않는다.
4. P0에서는 0.10 mm PET/PETG shim으로 스톱을 조정하거나 M2 × 4 무두나사를 사용한다.
5. 성인 사용자가 키캡에 10 N을 가해도 힘이 스위치가 아니라 쉘 스톱으로 전달되는지 정적 시험한다.
6. 하드스톱 접촉 뒤 추가 키캡 변위 목표는 0.10 mm 이하로 한다.
7. 스위치에 횡하중을 직접 가하지 않는다. LEFT/RIGHT 키도 가이드 면이나 키캡이 측압을 받고 플런저에는 축방향 힘만 전달해야 한다.

택트 스위치의 짧은 행정을 손끝 이동량으로 그대로 사용하면 방향 구분이 너무 예민해질 수 있다. 키 표면의 손끝 이동 목표 1~2 mm와 스위치 행정 약 0.6 mm를 맞추기 위해 키 형상에서 약 2:1~3:1의 변위비를 쓰되, 이 경우 손끝 작동력은 레버비에 따라 변하므로 P0에서 실측한다.

## 5. 직접 배선 기준

### 5.1 한 손가락 카트리지

```text
LEFT switch   ───────── signal L
CENTER switch ───────── signal C
RIGHT switch  ───────── signal R
세 스위치의 다른 단자 ─ common GND
```

카트리지 밖으로 `L / C / R / GND` 4선을 뽑는다. 네 카트리지는 MCP23017의 12개 GPIO에 연결한다.

- MCP23017 입력은 내부 풀업 활성화, 스위치는 눌렀을 때 GND로 연결한다.
- EVQ-P0E07K의 공식 저부하 범위는 10 µA/2 V부터이므로 3.3 V 풀업 입력에 적합하다.
- 폴링 1 kHz, 초기 디바운스 3 ms를 시작값으로 권장한다. 2~5 ms 범위에서 더블 입력률과 지연을 비교한다.
- 각 카트리지 커넥터 직전에 GND를 합친다. 스위치 사이를 딱딱한 단선으로 데이지체인하지 말고 AWG 28 연선을 사용한다.
- 납땜부에서 8~12 mm 떨어진 위치에 인쇄된 케이블 클램프를 두고, 단자에는 움직임이 전달되지 않게 5~8 mm의 느슨한 서비스 루프를 남긴다.
- 납땜부는 1.5~2 mm 열수축튜브로 절연한다. 핫멜트만으로 전기 절연과 인장 완화를 대신하지 않는다.

### 5.2 커넥터

카트리지 교체성을 위해 **JST-SM 4P 전선형 수·암 하네스**를 우선한다. PCB용 JST-PH/XH 헤더를 공중배선으로 쓰는 방식보다 전선형 커넥터가 조립 실수와 단선 위험이 적다.

핀 순서는 모든 손가락에 동일하게 고정한다.

```text
1 = GND (black)
2 = LEFT (blue)
3 = CENTER (white)
4 = RIGHT (yellow)
```

## 6. 4손가락·12입력 권장 BOM

### 6.1 구매 BOM

| 품목 | 규격 / 권장품 | 실사용 | 구매 권장 | 기준 단가·범위 | 예상 소계 | 비고 |
|---|---|---:|---:|---:|---:|---|
| 입력 스위치 | **Panasonic EVQ-P0E07K** | 12 | **15** | 디바이스마트 10개+ VAT 포함 550원 | **8,250원** | 3개는 선별·수리용 예비 |
| 대조 스위치(선택) | Omron B3F-1000 | 0 | 3 | VAT 포함 462원 이하, 수량 할인 변동 | 990~1,386원 | 힘 비교용, 최종품에는 비권장 |
| 카트리지 커넥터 | JST-SM 4P 수·암 프리와이어 세트 | 4 | 5 | 1,000~2,000원/세트, 판매처별 품질 편차 | 5,000~10,000원 | 1세트 예비 |
| 신호선 | AWG 28 연선, 4색 | 약 6 m | 색상별 2~3 m | 총 6,000~12,000원 | 6,000~12,000원 | 실리콘 연선 또는 UL1007 연선 |
| 열수축튜브 | 1.5 mm 및 2 mm | 약 1 m | 각 1 m | 2,000~4,000원 | 2,000~4,000원 | 단자별 절연 |
| 카트리지 체결나사 | M3 × 8~10 육각소켓머리 | 8 | 12 | 3,000~5,000원/팩 | 3,000~5,000원 | 본체 rail/마운트 체결 |
| 바닥 커버 나사 | M2 × 5 또는 M2 × 6 | 16 | 20 | 3,000~5,000원/팩 | 3,000~5,000원 | 카트리지당 4개 |
| LEFT/RIGHT 축 | Ø2mm 스테인리스 봉 | 약 116mm | 1m | 3,000~7,000원 | 3,000~7,000원 | 14.5mm × 8, 절단 여유 포함 |
| CENTER anti-loss pin | Ø1mm 스테인리스 봉 | 약 32mm | 0.5~1m | 2,000~5,000원 | 2,000~5,000원 | 4mm × 8, 절단 여유 포함 |
| 하드스톱 심 | 0.1/0.2/0.3mm PET shim | 방향별 선택 | 한 판 출력 | 사용분 500원 미만 | 0~500원 | 고정형 셸 스톱 미세보정 |
| 황동 열압입 인서트 | M2 및 M3, 길이 3~5mm | 24~28 | 각 20 | 6,000~12,000원 | 6,000~12,000원 | 커버 M2, 마운트 M3 |
| PETG | 카트리지·키·픽스처 | 약 180~250 g | 보유 필라멘트 사용 또는 1 kg | 사용분 5,000~8,000원 | 5,000~8,000원 | 신규 1 kg 구매 시 약 20,000~30,000원 |
| TPU | 교체식 손끝 패드 | 약 20~30 g | 보유품 사용 또는 1 kg | 사용분 1,000~2,000원 | 1,000~2,000원 | 신규 롤 구매 시 비용 증가 |
| 입력 확장 모듈 | MCP23017 완제품 모듈 | 1 | 1 | 기존 전체 BOM 가격 기준 약 10,000~15,000원 | 10,000~15,000원 | 커스텀 PCB 아님 |

**예상 합계**

- PETG/TPU를 보유하고 필요한 양만 원가 계산: 약 **55,000~88,000원**
- 필라멘트 롤과 공구성 부자재를 모두 새로 구매: 약 **90,000~140,000원**
- 배송비는 판매처 수에 따라 약 3,000~12,000원 추가될 수 있다.

가격은 2026-08-13 표시값 또는 국내 소매 범위다. 스위치 외 일반 기구부품은 규격과 묶음 수량에 따라 편차가 커서 임의의 단일 가격 대신 범위로 표시했다.

### 6.2 인쇄 부품 BOM

| 인쇄물 | 수량 | 재료 | 비고 |
|---|---:|---|---|
| finger cartridge shell | 4 | PETG | INDEX/MIDDLE/RING/PINKY 별도 폭·각도 |
| LEFT key/paddle | 4 | PETG | 플런저에는 축방향으로 힘 전달 |
| LEFT vertical follower | 4 | PETG | 캠 횡이동을 가이드가 받고 switch에는 축방향 힘 전달 |
| CENTER key | 4 | PETG | 약한 concave 접촉면 |
| RIGHT key/paddle | 4 | PETG | LEFT와 대칭이나 소지는 별도 치수 |
| RIGHT vertical follower | 4 | PETG | 측면 패들과 switch 사이 교체 부품 |
| 나사식 bottom cover | 4 | PETG | 3개 스위치를 동시에 교체·고정, 별도 클램프 불필요 |
| fingertip pad/cap | 12 | TPU | 0.8~1.2 mm 두께 시작값 |
| rear-exit 열수축/케이블타이 | 4 | 범용 | 출력물 내 별도 클램프 대신 배선 홈과 함께 사용 |

### 6.3 축·베어링

최종 V1 CAD는 Variant B 독립 패들을 채택했으므로 **Ø2mm 금속축이
필수**다. LEFT/RIGHT 각각 한 축, 즉 카트리지당 2개·4카트리지 총 8개를
사용한다. CENTER는 회전축이 아니라 2점 직선 가이드이며, 이탈 방지용 Ø1mm
핀 2개/카트리지를 사용한다.

- Variant A 직접 3스위치: 축 없음. 일정 백업안에만 해당한다.
- Variant B 독립 패들: Ø2mm 축 8개(약 14.5mm), Ø1mm pin 8개(약 4mm).
- Variant C 공유 로커: 공차·동시입력·복귀 위험 때문에 V1에서 제외한다.

Ø2mm 스테인리스 봉 1m를 절단해 쓰고 축 끝은 얇은 heat-shrink collar,
소형 shaft collar 또는 셸 캡으로 이탈을 막는다. 작은 별도 복귀 스프링은
사용하지 않고 스위치 자체 복귀력을 사용한다.

## 7. P0 최소 구매 목록

손가락 한 개짜리 fixture를 먼저 시험할 때 필요한 최소 수량이다.

| 품목 | 수량 |
|---|---:|
| EVQ-P0E07K | 6개: 사용 3 + 예비/선별 3 |
| M2 × 5/6 나사 | 6개 이상 |
| 0.1/0.2/0.3 mm PET U-shim | 방향별 실측 선택 세트 |
| M2 열압입 인서트 | 8개 이상 |
| JST-SM 4P 하네스 | 1세트 |
| AWG 28 연선 | 4색 각 0.5 m |
| 열수축튜브 | 0.3 m |
| PETG | 약 60~100 g |
| TPU | 약 5~10 g |

P0에서는 EVQ 3개와 B3F-1000 3개를 같은 fixture에서 교환해 비교하면 `0.74 N / 0.98 N` 차이가 약지·소지에 미치는 영향을 빠르게 확인할 수 있다.

## 8. 수입 검사 및 선별

15개 스위치를 바로 조립하지 말고 다음 순서로 검사한다.

1. 캘리퍼로 본체 X/Y/H를 측정하고 최대·최소 편차를 기록한다.
2. 멀티미터 continuity로 무부하 개방과 눌림 도통을 확인한다.
3. 간이 힘 게이지 또는 저울을 이용해 5회씩 작동시키고 작동력을 기록한다.
4. 클릭 후 복귀가 늦거나, 소리가 현저히 다르거나, 이중 도통이 있는 스위치는 예비로 분리한다.
5. 동일 손가락의 LEFT/RIGHT에는 작동력이 가까운 두 개를 짝지어 배치한다.
6. 가장 낮은 작동력 세 개는 소지, 다음은 약지에 우선 배치한다. 단, 지나치게 가벼운 이상품은 사용하지 않는다.

## 9. 검증 기준

스위치와 카트리지 조립 후 아래를 통과해야 한다.

- 각 방향 30회 입력에서 성공률 95% 이상.
- 인접 스위치 동시입력률 2% 이하를 목표로 하고, 5% 이상이면 키 각도·가드·프리로드를 수정한다.
- 10 N 정적 키 하중 후 스위치 높이와 작동점 변화가 측정 오차 이상 발생하지 않는다.
- 각 입력 10,000회 반복 후 missed/double activation 증가가 없다.
- 손가락을 키에서 떼지 않고 LEFT/CENTER/RIGHT 연속 입력이 가능하다.
- 소지 입력의 주관적 힘이 4/5 이상이면 레버비를 낮추거나 소지 전용 변위비를 적용한다. 더 강한 스위치로 바꾸지 않는다.

## 10. 최종 선택 요약

| 우선순위 | 선택 |
|---|---|
| V1 실물 제작 | **EVQ-P0E07K 12개 + 예비 3개** |
| 초고수명 비교안 | D2FC-F-7N(20M), 단 3.3 V 저전류 접점 신뢰성 별도 시험 필요 |
| M2 나사 고정이 꼭 필요한 비교안 | D2F-01F, 단 공식 최소 부하 조건 주의 |
| 저가 P0 대조군 | B3F-1000 3개 |
| 사용 금지 | 모델·힘·수명·데이터시트를 추적할 수 없는 무명 택트 스위치 |

V1에서는 **스위치 종류를 손가락마다 섞지 않는다.** 먼저 동일한 EVQ-P0E07K로 기구 형상과 레버비를 조절하고, 소지에 필요한 힘 차이는 스위치 변경보다 소지 전용 키 기구비로 해결한다. 그래야 교체성, 디바운스, 클릭감 관리가 단순해진다.

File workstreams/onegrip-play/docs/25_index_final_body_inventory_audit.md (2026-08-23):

# INDEX FINAL body inventory READ-ONLY audit

- 감사 대상: `INDEX_SHARED_RET_FINAL` (`6703cd9cbd0d5e321ac10b87`) →
  `INDEX_FINAL_VALIDATED` (`03ede76e83b5c865d9a69c35`)
- Part Studio: `Joystick` (`425d9199b59cfb1efd9ddc35`)
- 감사 방식: **Onshape GET only**
- CAD WRITE: **0건** — Feature 생성/수정/삭제/suppress 및 version 생성 없음
- 원시 결과: `cad_dump/index_final_body_inventory_audit.json`

## A. 동일 기준 최종 solid count

두 version을 아래의 완전히 동일한 기준으로 다시 계산했다.

```text
endpoint   GET /parts/d/a21e64f36bc61df760d4587c/v/{versionId}/e/425d9199b59cfb1efd9ddc35
filter     bodyType == "solid"
count      filter를 통과한 part record 수
```

| version | 전체 part record | solid | wire |
|---|---:|---:|---:|
| `INDEX_SHARED_RET_FINAL` | 19 | **17** | 2 |
| `INDEX_FINAL_VALIDATED` | 20 | **18** | 2 |

따라서 동일 기준의 실제 변화는 **solid 17 → 18**, 즉 **+1**이다.
현재 최종 solid count는 **18**이며 감소한 body는 없다.

두 wire는 양쪽 version에서 동일하다.

- `Curve 1` — `JMD`
- `Curve 2` — `RNDD`

### 최종 solid body inventory

부피는 같은 version-specific `massproperties?partId={partId}` 응답의 nominal
`volume[0] × 10^9`를 mm³로 환산했다.

| part name | partId | volume (mm³) | owning / creating feature | JaD/JfD | RWID | RZKD |
|---|---|---:|---|---|---|---|
| Joystick_1 | `JaD` | 47,492.700587 | `Enclose 1` `FdflGREM19IRypF_1` | **JaD** | — | — |
| Joystick_2 | `JfD` | 49,685.197185 | `Mirror 1` `FfyGpppYw8McLsz_2` | **JfD** | — | — |
| Backplate | `RYDD` | 5,899.945734 | `Sweep 1` `FR1RGAmsfokIVzQ_4` | — | — | — |
| Button_wide_1 | `RAED` | 288.485949 | `Extrude 17` `FN60hLJrErylbKr_5` | — | — | — |
| Button_side_1 | `RAEH` | 271.040394 | `Extrude 17` `FN60hLJrErylbKr_5` | — | — | — |
| Button_corner_1 | `RAEL` | 199.440181 | `Extrude 17` `FN60hLJrErylbKr_5` | — | — | — |
| Button_corner_2 | `RBED` | 199.440185 | `Extrude 23` `F5f2Bqv3P4yttCY_8` | — | — | — |
| Button_side_2 | `RBEH` | 271.040394 | `Extrude 23` `F5f2Bqv3P4yttCY_8` | — | — | — |
| Button_wide_2 | `RBEL` | 288.485949 | `Extrude 23` `F5f2Bqv3P4yttCY_8` | — | — | — |
| Button_middle_1 | `RDED` | 275.054087 | `Extrude 24` `FhTqxuAvjIWGQgW_11` | — | — | — |
| Button_middle_2 | `RDEH` | 275.054087 | `Extrude 24` `FhTqxuAvjIWGQgW_11` | — | — | — |
| Small_joystick_attachment | `RHED` | 284.540889 | `Extrude 25` `FTcXnBBgATAer7g_13` | — | — | — |
| Part 13 | `R4ED` | 231.040000 | `INDEX_button_caps` `FSAYT6HrIBkapCP_14` | — | — | — |
| Part 14 | `R9ED` | 231.040000 | `INDEX_button_caps` `FSAYT6HrIBkapCP_14` | — | — | — |
| Part 15 | `RCFD` | 231.040000 | `INDEX_button_caps` `FSAYT6HrIBkapCP_14` | — | — | — |
| Part 16 | `RHFD` | 231.040000 | `INDEX_button_caps` `FSAYT6HrIBkapCP_14` | — | — | — |
| Part 17 | `RWID` | 2,136.305048 | `RET_blank` `Fq5IPkiwWk5pWYv_15` | — | **YES** | — |
| Part 18 | `RZKD` | 284.959443 | `I4_retainer_blank` `F2N4HZlwCZvkovM_16` | — | — | **YES** |

## B. JaD

- `Joystick_1 = JaD`: **존재**, 이름·partId·ordinal 1 유지
- body 수: 1
- final volume: **47,492.700587 mm³**
- checkpoint 대비 nominal volume: **+74.799158 mm³**
- tessellation: 17,250 → 17,712 triangles
- 원인: 의도된 `I4_JaD_boss` (`FP31q74LciCNpK9_17`)와
  `I4_screw_hole` (`FWR7cU5dM92MTjy_17`) downstream geometry

JaD identity는 정상이며 split·소멸·partId 교체가 없다.

## C. JfD

- `Joystick_2 = JfD`: **존재**, 이름·partId·ordinal 2 유지
- body 수: 1
- final volume: **49,685.197185 mm³**
- B-rep topology: **276 vertices / 427 edges / 145 faces**, 두 version 동일
- topology entity ID set: vertices / edges / faces 모두 동일
- bodydetails vertex 최대 좌표 편차: **0.000000745 mm**
- tessellation 고유 정점 최대 최근접 편차: **0.00000273 mm**

그러나 immutable version끼리 새로 받은 raw tessellation은 strict SHA-256이 다르다.

| 항목 | checkpoint | final |
|---|---:|---:|
| triangles | 16,910 | 16,910 |
| canonical raw tess hash | `a04195a3...` | `f80d0cb5...` |
| tess mesh volume (mm³) | 49,670.423116 | 49,670.428521 |
| nominal massproperties volume (mm³) | 49,684.740878 | 49,685.197185 |

Onshape tessellation은 저장된 영구 형상이 아니라 요청 시 생성된다.
([Onshape Architecture](https://onshape-public.github.io/docs/api-intro/architecture/))
따라서 위 차이는 partId·topology·실질 표면이 바뀐 증거가 아니라 regeneration의
수치적 jitter로 판단된다. 0.01 mm 정규화 B-rep geometry hash는 동일하다.

다만 이번 감사의 strict 조건인 **“fingerprint/volume exact unchanged”**는
두 고정 version의 fresh GET 결과로 그대로 재현되지 않았다. 이 점은 최종 게이트에 반영한다.

## D. RWID

- shared retainer `RWID`: **존재**, single independent solid
- final volume: **2,136.305048 mm³**
- RZKD와 partId가 다르며 union되지 않음
- tessellation: **2,112 → 2,112 triangles**, canonical hash exact same
- tess mesh volume: **2,136.463389 → 2,136.463389 mm³**, exact same
- B-rep: **206 vertices / 312 edges / 108 faces**, exact same
- normalized full bodydetails SHA-256:
  `9f0ded67dca482344d8f382ba2e6a87f8edd1567ad7591af35c9e41556d013ce`
  — 양쪽 version exact same

`RET_blank`부터 `RET_hole_B`까지 shared feature 12개의 정의도 version 간 exact same이다.
따라서 RWID 본체, EAR_A′, EAR_B′, shared service relief는 무변화다.

## E. RZKD

- I4 retainer `RZKD`: **존재**, single independent solid
- final volume: **284.959443 mm³**
- creating feature: `I4_retainer_blank` (`F2N4HZlwCZvkovM_16`)
- RWID와 독립된 별도 part record이며 union·흡수 관계 없음
- checkpoint에는 없고 final에만 존재

따라서 **RWID와 RZKD는 서로 독립된 NEW PART**임이 확인됐다.

## F. checkpoint 간 added / removed / changed solids

### partId set diff

```text
added    RZKD
removed  none
```

소멸한 partId가 없으므로 union 흡수, suppression, 삭제 또는 body-loss는 발생하지 않았다.

### geometry diff 분류

| partId | 분류 | 근거 |
|---|---|---|
| `RZKD` | **ADDED — intended** | 별도 I4 retainer |
| `JaD` | **CHANGED — intended** | I4 boss + pilot/clearance downstream geometry |
| `JfD` | numeric regeneration drift | identity/topology 동일, raw hash·nominal volume만 극미세 차이 |
| `RYDD` | kernel regeneration/topology healing | V/E/F 186/283/85 → 184/281/85, face set 유지, nominal volume −0.063918 mm³ |

`RYDD`의 변경은 I4 boolean target이 아니다. I4의 JaD 선택점은 `z=-35mm`이고
RYDD bbox는 `z=28.547..73.368mm`이며, 나머지 I4 단계는 `qCreatedBy(RZKD)`만 대상으로 한다.
따라서 작성된 I4 형상이 Backplate를 절삭한 것이 아니라 전체 Part Studio regeneration에서
edge 두 개가 healing/reparameterization된 것으로 분류한다. body identity와 face 수는 유지된다.

그 외 공통 solid 14개는 nominal volume과 canonical tessellation fingerprint가 동일하다.

## G. 왜 19 → 18처럼 보고됐는가

원인은 **body 소멸이 아니라 counting rule 혼용**이다.

과거 retainer 실행기의 `scripts/run_retainer.py` `solids()`는 `/parts` 응답을
`bodyType` 필터 없이 전부 셌다. 따라서 다음을 “solid”라고 잘못 표기했다.

```text
holder 완료      16 actual solids + 2 wires = 기록 18
shared RWID 후   17 actual solids + 2 wires = 기록 19
```

I4 실행기의 `scripts/run_i4_retainer.py` health 집계는
`bodyType == "solid"` 필터를 사용하여 final을 18로 보고했다.

동일 규칙으로 다시 쓰면 다음 두 표현 모두 일관된다.

```text
all part records   19 -> 20
solid-only         17 -> 18
```

endpoint 자체는 `/parts`로 동일하다. 차이는 API endpoint, suppression 또는 regeneration이
아니라 **wire 2개를 포함했는지 여부**다.

양쪽 version에서 suppressed feature는 기존 `INDEX_switch_pockets`
(`FkGjuaVRtcptOX1_14`) 한 개로 동일하므로 count 차이에 영향을 주지 않는다.

## H. assembly / regeneration

| gate | checkpoint | final | 결과 |
|---|---:|---:|---|
| feature count | 174 | 180 | I4 6개 append |
| OK | 174 | 180 | PASS |
| ERROR | 0 | 0 | PASS |
| WARNING | 0 | 0 | PASS |
| isComplete | true | true | PASS |
| assembly instances | 25 | 25 | PASS |
| active instances | 25 | 25 | PASS |
| occurrences | 25 | 25 | PASS |
| suppressed instances | 0 | 0 | PASS |
| dangling | 0 | 0 | PASS |

assembly는 **25/25, dangling 0**이다.

## I. INDEX FINAL CONFIRMED / HOLD

### **INDEX FINAL SUCCESS = HOLD**

| final gate | 결과 |
|---|---|
| JaD 존재 / identity | PASS |
| JfD 존재 / identity | PASS |
| RWID independent part | PASS |
| RZKD independent part | PASS |
| ERROR 0 / WARNING 0 | PASS |
| assembly 25/25 | PASS |
| dangling 0 | PASS |
| solid-count 설명 | PASS — 17→18, 과거 wire 포함 오집계 |
| RWID/shared feature exact unchanged | PASS |
| JfD raw fingerprint + volume exact unchanged | **FAIL — fresh version-to-version GET에서 재현 안 됨** |

실제 solid 감소나 identity 손실은 없다. JfD 차이는 나노미터급 regeneration jitter이며
공학적으로는 동일하지만, 사용자 지시의 strict **exact fingerprint/volume** 조건을 임의로
완화하지 않는다. 따라서 원인만 보고하고 CAD는 수정하지 않는다.

## J. MIDDLE GO / HOLD

### **MIDDLE = HOLD**

body inventory와 count 문제 자체는 정상이다. 그러나 INDEX FINAL의 strict shared fingerprint
게이트 한 항목이 literal exact 기준을 통과하지 못했으므로 MIDDLE로 진행하지 않는다.

이번 감사 종료 시점까지 CAD WRITE는 **0건**이다.

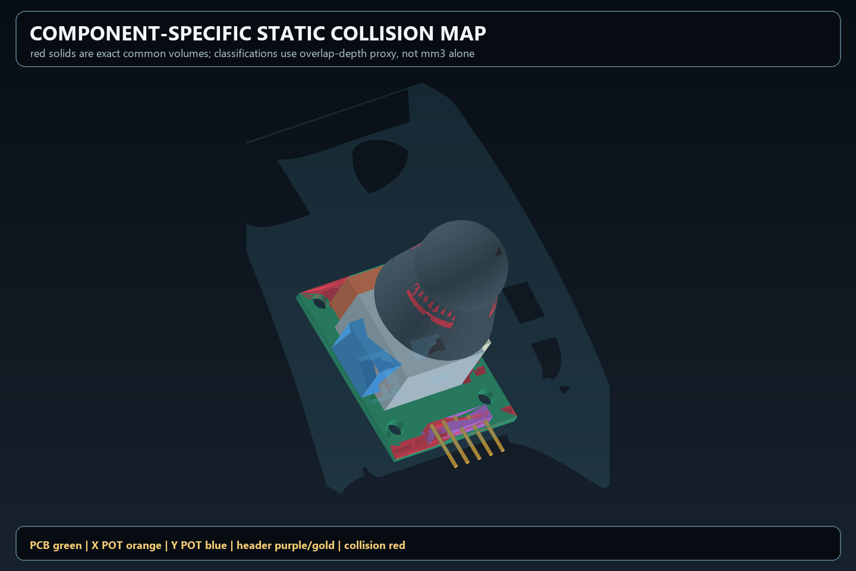
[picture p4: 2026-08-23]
workstreams/onegrip-play/renders/szh_ek056_provisional_thumb_integration_audit/05_component_specific_collision_map.png

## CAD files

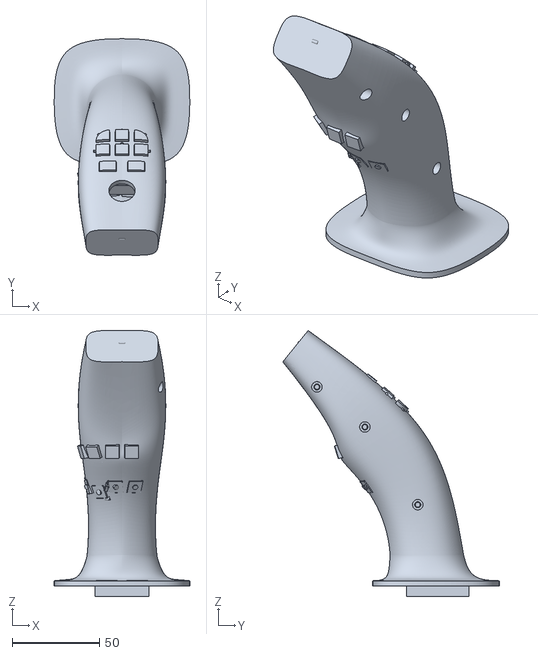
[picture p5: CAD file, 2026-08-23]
workstreams/onegrip-play/exports/full_exterior_minimal_mockup/OneGrip_Current_Main_Exterior_Mockup_SlicerUnion.stl
77.5 x 123.9 x 152.1

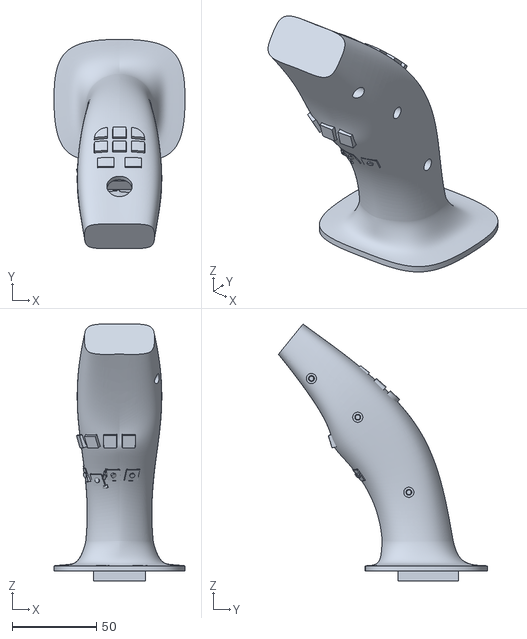
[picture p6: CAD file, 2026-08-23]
workstreams/onegrip-play/exports/full_exterior_minimal_mockup/OneGrip_Current_Main_Exterior_Alignment_Check.stl
77.5 x 123.9 x 152.1

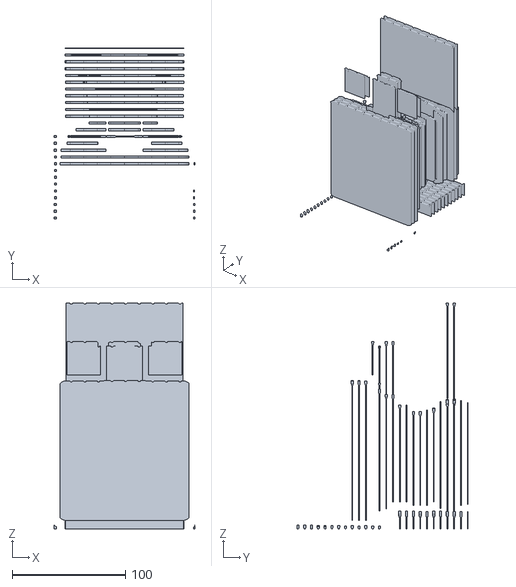
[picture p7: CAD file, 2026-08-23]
workstreams/onegrip-play/lower_adapter/local_cad/export/stl/MAIN_CUSTOM_SUPPORT_PLA.stl
124.5 x 151.4 x 199.6

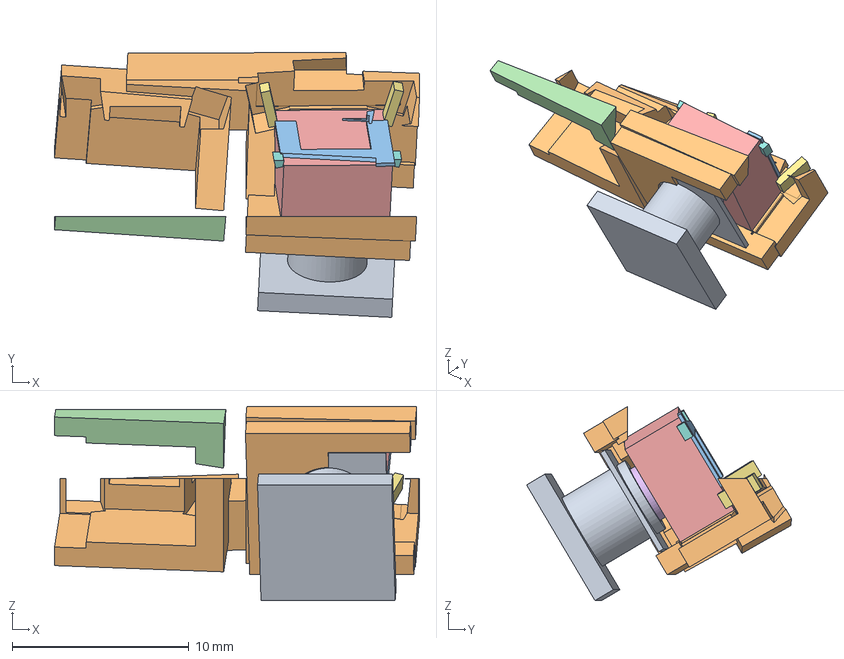
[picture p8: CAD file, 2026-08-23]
workstreams/onegrip-play/build123d_workbench/out/n2_production_intent_mechanism/N2_PRODUCTION_INTENT_LOCAL_ASSEMBLY.step
20.7 x 15.0 x 11.0 mm
N2_PRODUCTION_INTENT_CAP_DIRECT_ACTUATION
N1_N2_SHARED_CARRIER_N2_PRODUCTION_INTENT
N2_ITS1105_body
N2_ACTUATOR_COMPRESSED_0.000MM
N2_T1_ACTIVE_ELECTRICAL_TERMINAL
N2_T2_UNUSED_TRIMMED_STUB
N2_T3_ACTIVE_ELECTRICAL_TERMINAL
N2_T4_UNUSED_TRIMMED_STUB

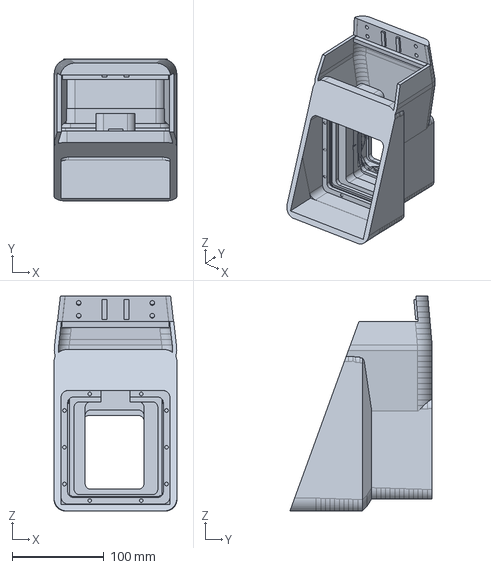
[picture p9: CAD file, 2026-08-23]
workstreams/onegrip-play/lower_adapter/local_cad/export/step/MAIN_PRODUCT_ONLY_PLA.step
133.6 x 154.6 x 233.8 mm

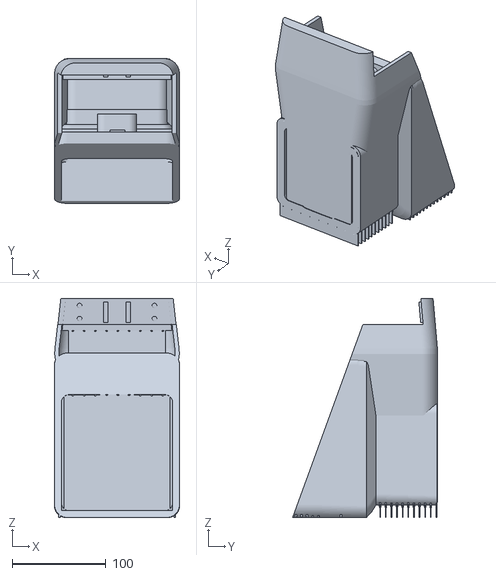
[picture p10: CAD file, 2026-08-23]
workstreams/onegrip-play/lower_adapter/local_cad/export/stl/HOUSING_V4_MAIN_PRINT_READY_PLA.stl
133.6 x 154.6 x 233.8

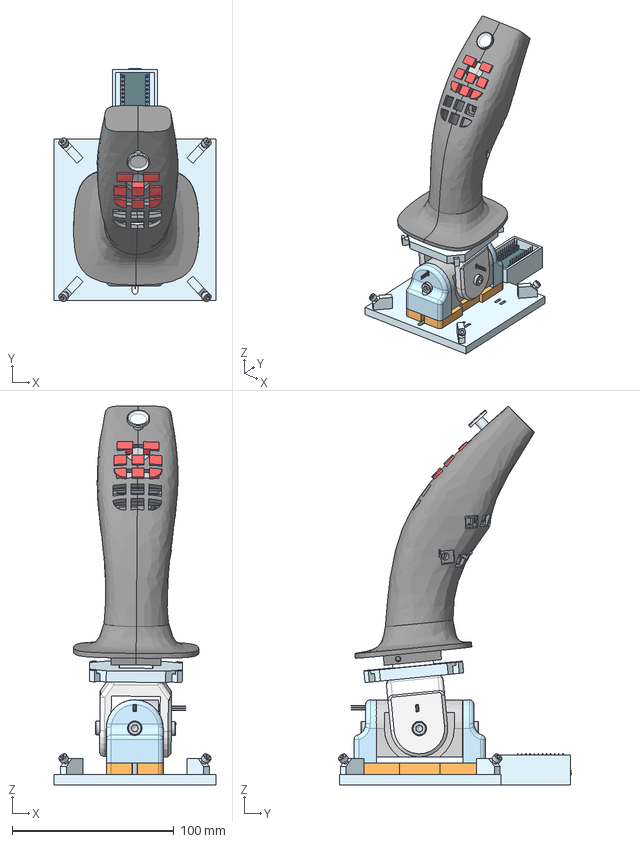
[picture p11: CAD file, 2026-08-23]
workstreams/onegrip-play/lower_adapter/local_cad/reference/ONEGRIP_LOWER_ASSEMBLY_REFERENCE.step
100.0 x 144.3 x 234.4 mm
Button_wide_2
HW504_B x 2
Button_side_2
Hex socket head cap screw M3x0.50 x 16 x 9
PushBtn x 8
Button_corner_1
Small_joystick_attachment
Button_middle_1
Button_corner_2
Button_wide_1
Backplate
Joystick_2
Button_middle_2
Button_side_1
Joystick_1
MICRO_led x 6
MICRO_603 resistor 22 x 8
MICRO_603 resistor 331 x 8
MICRO_603 resistor 102 x 4
SOD 323
MICRO_603 cap on pad x 7
MICRO_PTC-1206
MICRO_cap106C x 2
atmega32U4
micro_crystal 5x3
MICRO_603 resistor 103 x 4
micro_MIC5219
MICRO_stackable header pin x 24
MICRO_stackable header 12 x 2
micro usb shell
micro usb contact x 5
micro usb internal
micro board
Base
Spring_holder
Magnet x 4
Roll_holder_2
Pitch
Hex socket head cap screw M5x0.80 x 12 x 4
Roll
Outer_racing x 4
Ball_4 x 4
Ball_1 x 4
Ball_7 x 4
Inner_racing x 4
Ball_6 x 4
Ball_3 x 4
Ball_5 x 4
Ball_8 x 4
Ball_2 x 4
Roll_holder
Spacer

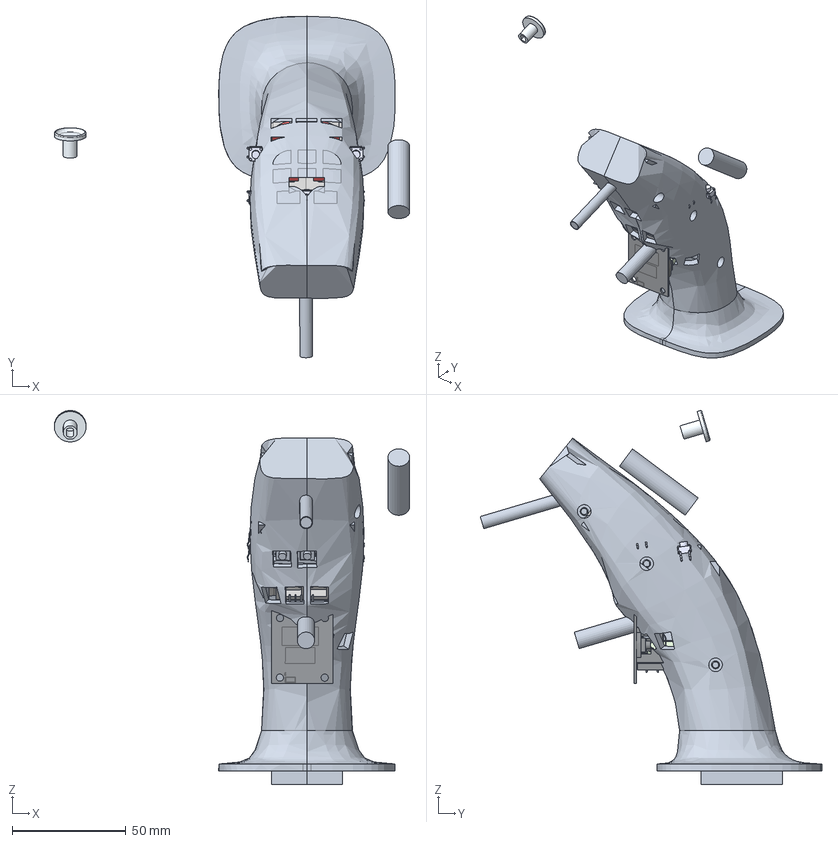
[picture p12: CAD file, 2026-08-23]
workstreams/onegrip-play/build123d_workbench/out/hw504_minimal_change_candidates/FULL_COMPARISON_REFERENCE.step
156.0 x 149.9 x 164.2 mm
Backplate
Button_corner_1
Button_middle_1
Button_corner_2
Button_side_1
Button_middle_2
Button_side_2
Button_wide_1
Button_wide_2
PushBtn x 8
HW504_B
CANDIDATE_B_HW504_B_NONFUNCTIONAL_TRIM
Small_joystick_attachment
JAD_EXTERIOR_LOWERED_THUMB_V1
JFD_EXTERIOR_LOWERED_THUMB_V1
N1_ITS1105_body
N1_ITS1105_actuator
N1_root_nu_nv
N1_root_nu_pv
N1_root_pu_nv
N1_root_pu_pv
N2_ITS1105_body
N2_ITS1105_actuator
N2_root_nu_nv
N2_root_nu_pv
N2_root_pu_nv
N2_root_pu_pv
N1_N2_shared_C_channel_carrier
JAD_INTERNAL_BACKPLATE_ADAPTER_HALF
JFD_INTERNAL_BACKPLATE_ADAPTER_HALF
NEUTRAL_STICK_AXIS_N__EXACT_OBSERVED_RADIUS
NEUTRAL_STICK_AXIS_N__PROTECTED_GUARD
PIVOT_AXIS_U__EXACT_OBSERVED_RADIUS
PIVOT_AXIS_U__PROTECTED_GUARD
PIVOT_AXIS_V__EXACT_OBSERVED_RADIUS
PIVOT_AXIS_V__PROTECTED_GUARD

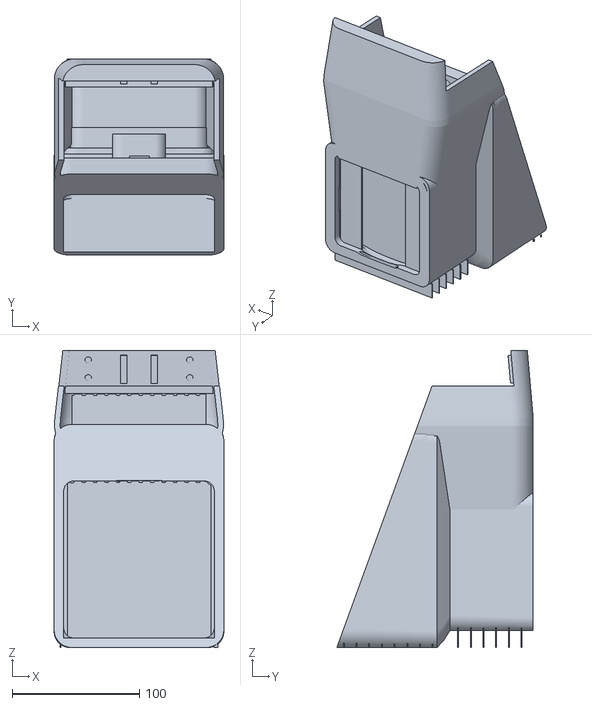
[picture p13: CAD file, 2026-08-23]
workstreams/onegrip-play/lower_adapter/local_cad/export/stl/HOUSING_V4_MAIN_PRINT_READY_PLA_V1.stl
133.6 x 154.6 x 233.8

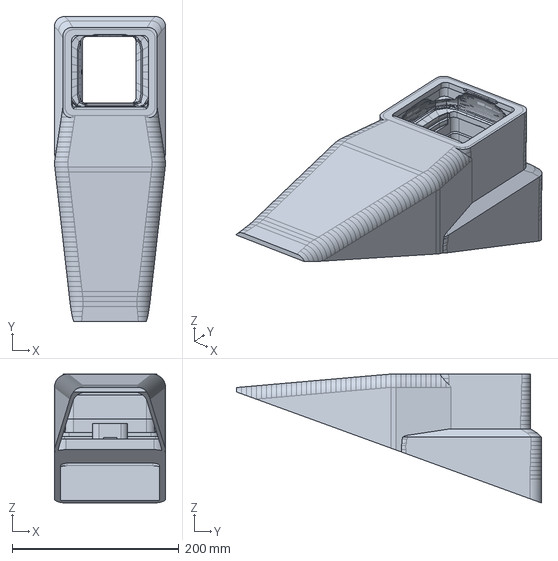
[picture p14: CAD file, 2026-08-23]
workstreams/onegrip-play/lower_adapter/local_cad/export/step/HOUSING_V4_SPLIT_ASSEMBLED_REV_D.step
133.6 x 365.8 x 154.6 mm

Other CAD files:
workstreams/onegrip-play/build123d_workbench/out/finger_controls_v2/FINGER_V2_ASSEMBLY_REFERENCE.step
workstreams/onegrip-play/lower_adapter/local_cad/export/step/HOUSING_V4_MAIN_PRINT_REV_B.step
workstreams/onegrip-play/lower_adapter/local_cad/export/step/HOUSING_V4_MAIN_PRINT_REV_C.step
workstreams/onegrip-play/lower_adapter/local_cad/export/step/MAIN_PRINT_READY_PLA_V1.step
workstreams/onegrip-play/lower_adapter/local_cad/export/step/HOUSING_V4_MAIN_PRINT.step
workstreams/onegrip-play/lower_adapter/local_cad/export/step/HOUSING_V4_SPLIT_ASSEMBLED_REV_C.step
workstreams/onegrip-play/lower_adapter/local_cad/export/step/HOUSING_V4_SPLIT_ASSEMBLED.step
workstreams/onegrip-play/lower_adapter/local_cad/export/step/ERGO_HOUSING_25_WRAP_W134_FULLSIDE.step
cad/finger-input-v1/test_fixture/hard_stop_shim_profile.dxf
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

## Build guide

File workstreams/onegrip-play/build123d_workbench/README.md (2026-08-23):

# OneGrip build123d workbench

This isolated workbench carries the verified `FINGER_SIMPLIFIED_CARRIER_V1`
coordinates into a local, scriptable build123d baseline.

## Bootstrap

From the repository root in PowerShell:

```powershell
.\scripts\setup_build123d.ps1
```

## Rebuild exports

```powershell
.\.venv-build123d\Scripts\python.exe -m build123d_workbench.export_baseline
```

## Validate

```powershell
.\.venv-build123d\Scripts\python.exe -m build123d_workbench.smoke_test
```

## MIDDLE redesign

Build the exact OCC parts, run the local collision/assembly gates, and export
STEP/STL:

```powershell
.\.venv-build123d\Scripts\python.exe -m build123d_workbench.validate_middle_redesign
```

Create the six visual-QC images and the print-oriented six-part plate:

```powershell
.\.venv-build123d\Scripts\python.exe -m build123d_workbench.render_middle_redesign
.\.venv-build123d\Scripts\python.exe -m build123d_workbench.prepare_middle_print_stl
```

The MIDDLE redesign is defined in `middle_redesign.py`; its manufacturing
parameters are grouped at the top of that module. It contains no Onshape
client code, and running these commands performs zero CAD writes.

Generated STEP/STL files and a JSON manifest are written to `out/` and are
intentionally ignored by Git. The exact Onshape source meshes remain in their
existing `exports/` directories and are never modified by this workbench.

The Python package is named `build123d_workbench` deliberately; a local module
named `build123d` would shadow the installed dependency.

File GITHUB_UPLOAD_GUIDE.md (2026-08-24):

# GitHub 업로드 안내

## 권장 업로드 순서

1. `OneGrip_Play_GitHub_업로드용_20260824.zip`의 압축을 푼다.
2. 압축 내부의 `OneGrip_Play/` 폴더에서 Git 저장소를 만든다.
3. `README.md`의 이미지와 상대경로 링크가 보이는지 확인한다.
4. 소스·문서·검증 결과를 기본 저장소에 올린다.
5. 조립 배포용 ZIP은 저장소에 반복해서 넣지 말고 GitHub Releases에 첨부한다.

```powershell
git init
git add .
git commit -m "Add OneGrip Play prototype design and validation files"
git branch -M main
git remote add origin <GitHub 저장소 주소>
git push -u origin main
```

## ZIP 구성 원칙

포함:

- 루트 `README.md`와 설계·부품 문서
- 현재 채택한 Full Module V3
- 검지·중지 8버튼 카세트 V2
- 3방향 손가락 입력 연구안
- RP2040·전원보드 서비스 카세트
- 팀원 최신안·Claude Code 최소 재현 원본
- 분석 스크립트와 검증 결과
- 전시 포스터 PPTX·PDF·PNG
- 제3자 출처와 라이선스 고지

제외:

- `.git/`
- `__pycache__/`, `.pyc`
- 포스터 백업·inspect 파일
- 전체 Desktop 체크포인트와 중간 캐시
- 중복된 구형 배포 ZIP
- 1 GB가 넘는 손 크기 실험용 중간 출력물

## 재현성 참고

`cad/onegrip-full-module-v3/build_full_module_blender.py`는 저장소 내부의
`cad/source_snapshot/team_claude_latest/`를 우선 사용한다. 원래 팀원 Desktop
작업 폴더가 없는 다른 컴퓨터에서도 필요한 상부 쉘·엄지·하부 짐벌 원본을 찾을
수 있도록 수정했다.

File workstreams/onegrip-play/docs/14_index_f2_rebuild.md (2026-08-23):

# INDEX F2 재생성 — 실행 기록 및 실물 검증

- 일자 2026-08-19
- 승인 근거: `docs/13_index_axis_collision_optimization.md` (F2 안 승인)
- 체크포인트 버전: **`F2_rebuild_start`** (`1bbe0311bfa8ecdc32a4a06d`) — 수정 직전 생성
- WRITE 대상: `OneGrip_Play_V1` did `a21e64f36bc61df760d4587c` / wid `ef6a7b3ccc45186203e4d2ca`
- 결과 요약: **형상 재생성은 성공. 단 실물 검증에서 §14 HOLD 조건 2건 발생 → 보고 후 중단.**

---

## 0. 실행 방식 — 왜 피처를 지우고 다시 만들지 않았는가

Onshape `POST /features` 는 트리 **최하단에만** 추가한다. 중간 삽입이 없다.
front trim 은 blank 와 union 사이에 있어야 하므로, 삽입을 하려면 기존 파이프라인
전체(약 30개 피처)를 지우고 다시 쌓아야 한다.

대신 **Feature Studio 소스를 고치면 기존 인스턴스가 전부 자동 재생성된다**는 성질을 썼다.

| 필요한 변경 | 실행 방법 |
|---|---|
| I1~I4 축을 F2 로 | FS 의 `IDX` 상수 교체 → 모든 stage 자동 반영 |
| front trim 단계 추가 | **`GROOVE` stage 를 front trim 으로 전환** (트리 위치가 이미 blank~union 사이) |
| 개별 retainer plug 폐기 | `RETAINER` stage 를 no-op 으로 |
| front lip 0.8 → 1.5 | FS 상수 `LIP_F2` (§0.1 참조) |

- enum 식별자 `GROOVE` / `RETAINER` 는 **기존 feature JSON 호환을 위해 유지**했고,
  표시명만 `E3 front trim` / `G unused (retired)` 로 바꿨다.
- **stage 단위로 바뀌므로 feature ID 를 추측할 필요가 없다.** 해당 stage 인스턴스만 정확히 변한다.
- 각 stage 는 여전히 **버튼 1개, target = 그 blank 하나뿐**이다. 쉘은 negative target 이 아니다.

### 0.1 `#finger_switch_front_lip` — FS 상수로 처리한 이유

트리 변수 피처를 수정하려면 그 featureId 가 필요하고, 그러려면 `GET /features` 가 필요하다.
이 엔드포인트가 **429 (Retry-After ≈ 10,363 s ≈ 2.9 시간)** 라 접근할 수 없었다.

→ FS 안에 `const LIP_F2 = 1.5 * millimeter;` 로 두고 `getVariable` 대신 사용했다.
**형상은 승인값 1.5 mm 로 정확히 만들어졌다.** 트리 변수 `#finger_switch_front_lip`(0.8)은
현재 아무 데서도 읽히지 않는 사문(死文)이다.
**후속 정리 항목:** rate limit 해제 후 트리 변수를 1.5 로 바꾸고 `getVariable` 로 되돌린다.

### 0.2 컴파일 실패 1회와 원인

첫 업로드에서 `featureSpecs` 가 비었다(컴파일 실패). 원인은
**RETAINER 를 no-op 으로 만들면서 `const clr` 이 미사용이 된 것**이다.
FeatureScript 는 **미사용 지역변수를 경고가 아니라 에러로 처리한다.**
해당 선언을 지우자 즉시 컴파일 성공(`idxHolderAtomic`).

---

## 1. 실제로 만들어진 형상

### 1.1 CLEARNBR 폭 정정 (중요)

기존 CLEARNBR 은 `#finger_retainer_groove_width`(7.4 mm)를 썼다.
groove 가 없어진 지금 7.4 를 그대로 두면 **이웃 포켓 표면을 0.5 mm 넘어 파내
0.80 mm 칸막이가 0.30 mm 로 줄어든다.** → 폭을 `pockW`(6.4 mm)로 바꿨다.
이제 CLEARNBR 기둥의 단면이 이웃 seat 와 정확히 같아 칸막이가 온전히 남는다.

### 1.2 깊이 체계 (front lip 1.5 반영)

```
쉘 벽            0 … 3.0      (n0 기준)
front trim 평면  n0 깊이 2.8   ← blank 앞면
스위치 앞면      축 깊이 4.5   (= 3.0 + 1.5)
스위치 뒷면      축 깊이 10.5
seat 끝          축 깊이 10.7
blank 뒤끝       축 깊이 13.2  (= seatTo + #finger_retainer_thickness 2.5)
holder 단면      12.4 × 12.4
```

---

## 2. 최종 보고 (A ~ M)

### A. F2 holder 재생성 성공 여부 — **성공**

| 항목 | 결과 |
|---|---|
| FS 컴파일 | OK (`idxHolderAtomic`), 실패 1회는 §0.2 |
| solid body | **22 → 18** (retainer plug 4개 소멸, 캡 4개 유지) |
| regeneration | 오류 없음 (형상 정상 생성) |
| 시트 단면 실측 | **모든 버튼·모든 깊이에서 축→벽 3.200 mm** = 정확히 6.4 × 6.4 |
| 분할면 clip | I3/I4 모두 적용 확인 |

### B. I1~I4 최종 axes — 승인값 그대로 반영됨

```
I1 = (-0.814063, -0.500337, -0.294898)   법선편차 16.46°
I2 = (-0.406762, -0.574504, -0.710274)   법선편차 16.46°
I3 = (-0.074927, -0.997095, -0.013664)   법선편차 16.32°
I4 = (+0.038301, -0.955619, -0.292106)   법선편차  0.00°
```

### C. exact SAT pair clearances (정확 SAT, vertex distance 미사용)

**설계 위치(스위치 앞면 축깊이 4.5 mm) 기준 — 승인 조건 충족:**

| 쌍 | 여유 |
|---|---|
| **I1-I2** | **1.200006 mm** |
| **I2-I3** | **1.199996 mm** |
| I1-I3 | 5.639622 mm |
| I3-I4 | 3.797530 mm |
| I1-I4 | 14.056 mm |
| I2-I4 | 10.143 mm |

→ 최소 **1.200 mm**, 조건 ≥ 1.20 **충족** (수치해 정밀도 ±4e-6).

**그러나 실제 착좌 위치 기준으로는 미달한다 → §3 참조.**

| 쌍 | 실제 착좌 깊이 기준 여유 |
|---|---|
| **I1-I2** | **1.145 mm** ← 조건 미달 |
| I2-I3 | 1.200 mm |
| I1-I3 | 5.086 mm |
| I3-I4 | 3.723 mm |

### D. minimum divider thickness — **0.648 mm (HOLD 조건 해당)**

CAD 실제 포켓(6.4 × 6.4, 축깊이 4.5 ~ 10.7) 사이 최소거리:

| 쌍 | 칸막이 |
|---|---|
| I1-I2 | 0.705 mm |
| **I2-I3** | **0.648 mm** |
| I3-I4 | 3.376 mm |
| I1-I3 | 5.124 mm |

> **예측 0.80 mm 와 다른 이유:** 0.80 은 `스위치 여유 1.200 − 2×0.2` 로 계산했는데,
> 이는 최근접이 **측방**일 때만 맞다. 실제 포켓은 스위치(6.0)보다 **뒤로 0.2 mm 더 길고**
> (4.5 ~ 10.7), 그 뒷부분이 축이 더 수렴하는 구간에 들어가 최근접점이 된다.
> **칸막이는 스위치가 아니라 포켓으로 구속했어야 한다.** 이번에 확인된 모델 보정 사항이다.

### G. screw minimum 3D clearance — **2.27 mm (조건 2.5 미달)**

| | I1 | I2 | I3 | **I4** |
|---|---|---|---|---|
| 나사 B 3D 최소거리 | 4.09 | 4.41 | 4.37 | **2.27 mm** |

원인은 축이 아니라 **홀더 후단 깊이**다. front lip 0.8 → 1.5 로 늘리면서
`blankTo = seatTo + #finger_retainer_thickness` 가 12.5 → **13.2 mm** 로 깊어졌고,
I4 의 축 방향(−a = +Y, +Z)이 나사 B(Y −14.45, Z 23.07) 쪽이라 0.7 mm 만큼 가까워졌다.

| blankTo | I1 | I2 | I3 | I4 | 최소 |
|---|---|---|---|---|---|
| **13.2 (현재)** | 4.09 | 4.41 | 4.37 | **2.27** | **2.27** |
| 12.8 | 4.47 | 4.81 | 4.47 | 2.62 | 2.62 |
| 12.5 (F2 이전) | 4.75 | 5.11 | 4.56 | 2.89 | 2.89 |
| **11.7** | 5.52 | 5.91 | 4.84 | **3.60** | **3.60** |

개별 twist-lock plug 를 폐기했으므로 `#finger_retainer_thickness`(2.5 mm) 예비 공간은
더 이상 필요 없다. 스위치 뒷면이 10.5, seat 끝이 10.7 이므로 **blankTo = 11.7 이면
후면 여유 1.0 mm 를 두고도 나사 B 여유가 3.60 mm 로 회복된다.**

### H. I3/I4 split ownership — **PASS**

| | 포켓 X 범위 | 요구 | 판정 |
|---|---|---|---|
| I3 | −8.301 … **−1.463** | X ≤ 0 | **PASS** (분할면 벽 1.46 mm) |
| I4 | **+1.855** … +8.555 | X ≥ 0 | **PASS** (분할면 벽 1.86 mm) |

holder blank 자체는 여전히 분할면을 넘으므로(I3 → +1.68, I4 → −1.28) `SPLITCLIP` 이 필요하며,
실물에서 **적용 확인**했다: JfD 안에 X>0 인 I3 홀더 재료 0개, JaD 안에 X<0 인 I4 홀더 재료 0개.

### I. JaD / JfD identity — **PASS**

| 항목 | 결과 |
|---|---|
| `JaD` (Joystick_1) | 유지, body 1개 |
| `JfD` (Joystick_2) | 유지, body 1개 |
| body split | 없음 |
| 신규 partId | 없음 |

### J. assembly integrity — **PASS**

`Joystick` 어셈블리 **occurrences 25 / instances 25**, `JaD`·`JfD` 참조 정상.
삭제된 plug(`RWID`/`RmID`/`R2ID`/`RGJD`)를 참조하는 dangling instance **0개**
(전체 어셈블리 9개 모두 확인).

### K. old twist-lock geometry 제거 — **완료, 그리고 이것이 곧 라이브 검증이다**

`RETAINER` stage 를 no-op 으로 바꾼 직후 `GET /parts` 결과:

```
소멸: RWID(Part 17)  RmID(Part 18)  R2ID(Part 19)  RGJD(Part 20)   ← 4/4
유지: R4ED(Part 13)  R9ED(Part 14)  RCFD(Part 15)  RHFD(Part 16)   ← INDEX 캡 4/4
JaD / JfD 무변화
```

> **이것이 §5 가 요구한 라이브 확인을 대체·충족한다.**
> ID 를 믿고 삭제한 것이 아니라, **stage 를 no-op 으로 만들었더니 정확히 그 4개 body 만
> 사라졌다.** 즉 "RETAINER stage 인스턴스 4개 = Part 17~20 의 생성자"이며
> `JaD`/`JfD` 와 무관함이 실물로 증명되었다.
> groove 역시 stage 전환으로 형상이 사라졌다(별도 body 를 만들지 않던 절삭이었다).
>
> **다만 피처 자체는 아직 트리에 남아 있다** (no-op 스텁 / front trim 으로 전용).
> `GET /features` 가 429 라 이름 대조를 못 했으므로 **삭제는 하지 않았다.**
> retainer 스텁 4개는 rate limit 해제 후 이름 확인하고 지운다.

### E. opening / stem clearance — **PASS** (실물 측정)

| | 축선상 재료 | 4.5 mm 보어 ↔ 8×8 개구부 최소여유 |
|---|---|---|
| I1 | **없음 (완전 관통)** | **0.769 mm** |
| I2 | 없음 | 0.772 mm |
| I3 | 없음 | 0.780 mm |
| I4 | 없음 | 1.750 mm |

기존 8×8 개구부를 재생성하지 않고도 **잠정 4.5 mm stem bore 가 그대로 통과**한다.
docs/13 §13-G 의 예측(0.769 / 0.772 / 0.780 / 1.750)과 **완전히 일치**한다.

### F. cap underside 수정 — **미수행 (다음 단계)**

이번 실행에서 캡은 건드리지 않았다. 외형·외부 중심 모두 원래대로다.
정합성만 재계산했고, **수정 없이도 기구학적으로 성립**한다:

| | 캡 이동축(n0) ↔ 플런저축 | 행정 0.25 mm 당 측방 어긋남 | 캡 여유 |
|---|---|---|---|
| I1 | 16.46° | **0.0708 mm** | 0.20 mm |
| I2 | 16.46° | 0.0708 mm | 0.20 mm |
| I3 | 16.32° | 0.0703 mm | 0.20 mm |
| I4 | 0.00° | 0.0000 mm | 0.20 mm |

docs/13 예측(0.071 mm)과 일치. 남은 작업은 **캡 밑면에 축 방향으로 기운 평면 접촉 패드**를
붙이는 것뿐이며, 외부 형상 변경은 필요 없다.

---

## 3. HOLD 조건 3건 — 실물 검증에서 드러난 것

형상 재생성 자체는 성공했지만, **설계 위치가 아니라 실제 실현 위치**로 재평가하면
승인 기준 3개가 미달한다. §5·§13·§14 의 HOLD 지시에 따라 **여기서 중단하고 보고한다.**

### HOLD-1. 스위치가 설계보다 깊게 들어가야 한다 → 여유 1.200 → **1.145 mm**

**현상.** 6 × 6 단면을 축을 따라 훑으면 설계 앞면 깊이 4.5 mm 에서 아직 재료가 남아 있다.

| 깊이(mm) | 4.50 | 4.60 | 4.70 | 4.80 | 4.90 | 5.00 | 5.10 | 5.20 |
|---|---|---|---|---|---|---|---|---|
| I1 | 22 | 2 | 1 | 1 | **0** | 0 | 0 | 0 |
| I2 | 33 | 1 | **0** | 0 | 0 | 0 | 0 | 0 |
| **I3** | 42 | 7 | 5 | 4 | 3 | 2 | 1 | **0** |
| I4 | 30 | **0** | 0 | 0 | 0 | 0 | 0 | 0 |

(169개 표본 중 재료와 겹치는 점 수. 0 이 되는 깊이가 실제 최소 착좌 깊이)

→ **실제 착좌 깊이 = I1 4.90 / I2 4.70 / I3 5.20 / I4 4.60 mm** (설계 4.50)

**원인.** 막는 재료는 홀더가 아니라 **기존 8 × 8 개구부 바깥의 쉘 벽**이다.
n0 국소좌표 y0 = −4.10 (개구부 경계 바로 바깥)에서 벽을 관통 측정하면:

```
y0 = -4.10, x0 = -2.74  ->  재료 [0.92 , 4.10]  두께 3.18 mm
y0 = -4.10, x0 = -1.29  ->  재료 [0.64 , 3.80]  두께 3.16 mm
y0 = -4.10, x0 =  0.00  ->  재료 [0.50 , 3.62]  두께 3.12 mm
y0 = -3.50, x0 =  0.00  ->  재료 [2.80 , 3.68]  두께 0.88 mm   ← 개구부 안: 홀더 lip (정상)
```

그립이 볼록하므로 개구부 바깥으로 갈수록 **외피가 내려앉아** 벽의 안쪽면이
n0 깊이 **3.62 ~ 4.10 mm** 까지 내려온다. 축을 16.5° 기울이면 스위치 앞면의 한쪽 모서리가
그 영역으로 올라가 걸린다. (t=0 이었을 때는 앞면이 벽과 평행해 생기지 않던 문제다)

**결과.** 실제 착좌 위치 기준 SAT 최소 여유 **1.145 mm** (요구 ≥ 1.20).

> **docs/13 의 모델 결함:** front lip 제약을 "n0 깊이 ≥ 트림면 2.8 + 0.5" 로 걸었는데,
> 실제 기준면은 평평한 2.8 이 아니라 **곡률로 최대 4.10 까지 내려오는 쉘 안쪽면**이다.

### HOLD-2. 포켓 칸막이 **0.648 mm** (승인 0.80, HOLD 조건 < 0.80)

§2-D 참조. 원인은 **칸막이를 스위치(6.0)가 아니라 포켓(6.4 × 6.4 × 6.2)으로 구속했어야**
하는데 그러지 않은 것이다. 포켓이 스위치보다 뒤로 0.2 mm 더 길고, 그 뒷부분이
축이 더 수렴하는 구간에 들어가 최근접점이 된다.

F2 축을 유지한 채 앞면 깊이만 바꿔도 해소되지 않는다:

| 앞면 깊이 | 스위치 최소 여유 | 칸막이 최소 |
|---|---|---|
| **4.5 (설계)** | **1.200** | **0.648** |
| 5.0 | 1.062 | 0.567 |
| 5.2 | 1.006 | 0.511 |
| 6.0 | 0.872 | 0.317 |

깊게 넣을수록 나빠진다. **축을 다시 풀어야 한다.**

### HOLD-3. I4 홀더 ↔ 나사 B **2.27 mm** (요구 ≥ 2.5)

§2-G 참조. 축 문제가 아니라 **홀더 후단 깊이**(12.5 → 13.2)가 원인이며,
개별 plug 폐기로 불필요해진 `#finger_retainer_thickness`(2.5 mm) 예비를 줄이면 해소된다.
**blankTo = 11.7 mm → 나사 B 여유 3.60 mm** (기준선 2.89 보다 오히려 개선).

이 항목은 **축과 무관한 독립 수정**이며 위험도가 낮다.

---

## 4. 수정안 (계산 완료, CAD 미적용 — 승인 대기)

### 수정안 ①: 칸막이를 **포켓 기준**으로 다시 구속 (HOLD-2)

제약을 `포켓(6.4×6.4×6.2) 최소거리 ≥ 0.80` + `스위치 ≥ 1.20` + `분할벽 ≥ 1.5` 로 두고
자유축 minimax 를 다시 풀면:

| 앞면 깊이 | 최대 편차 | 칸막이 | 스위치 여유 | 분할벽 | I4 편차 |
|---|---|---|---|---|---|
| **4.5** | **17.12°** | **0.800 mm** | **1.347 mm** | 1.50 mm | **0.00°** |
| **5.0** | **17.17°** | **0.800 mm** | **1.348 mm** | 1.50 mm | **0.00°** |

**F2 의 16.46° 대비 +0.66° 로 칸막이 0.648 → 0.800 mm 를 회복한다.**
스위치 여유도 1.200 → 1.347 mm 로 함께 올라간다 (칸막이 구속이 더 강한 조건이기 때문).

> **중요:** 축을 다시 풀면 **앞면 깊이를 4.5 → 5.0 으로 옮겨도 편차가 0.05° 밖에 안 는다.**
> 즉 HOLD-1(착좌 깊이)과 HOLD-2(칸막이)를 **한 번의 재최적화로 동시에 해결할 수 있고,
> 개구부를 건드릴 필요가 없다.** 앞면 깊이는 새 축에 대해 착좌 깊이를 실측한 뒤 확정한다.

### 수정안 ②: 홀더 후단 깊이 축소 (HOLD-3)

```
현재:  blankTo = seatTo + #finger_retainer_thickness(2.5) = 13.2 mm  -> 나사 B 2.27 mm
제안:  blankTo = seatTo + 1.0                            = 11.7 mm  -> 나사 B 3.60 mm
```
스위치 뒷면 10.5 / seat 끝 10.7 이므로 후면 여유 1.0 mm 는 충분하다.
개별 plug 를 폐기했으므로 2.5 mm 예비는 근거가 없어졌다.
**축·여유·칸막이에 영향 없는 독립 수정.**

### 수정안 ③: 착좌 깊이 — **재최적화에 흡수된다 (개구부 수정 불필요)**

쉘 + 기존 8×8 개구부만 있는 상태(홀더 없음 = 축 후보 평가의 올바른 기준)에서
6 × 6 스위치가 재료와 겹치지 않는 최소 깊이를 실측하면:

| 축 | I1 | I2 | I3 | I4 | **필요 앞면 깊이** |
|---|---|---|---|---|---|
| F2 (현재 CAD) | 4.75 | 4.70 | 5.15 | 4.30 | **5.15 mm** |
| 수정안 축 | 4.60 | 4.75 | 5.25 | 4.30 | **5.25 mm** |

앞면 깊이를 5.3 mm 로 두면 충족되고, 그 깊이에서 재최적화한 축은:

| 앞면 5.3 (lip 2.3) | 값 |
|---|---|
| 최대 편차 | **17.21°** |
| 칸막이 | **0.800 mm** |
| 스위치 여유 | **1.348 mm** |
| 분할면 벽 | 1.50 mm |

```
I1 = (-0.851033, -0.500047, -0.160298)
I2 = (-0.393870, -0.571110, -0.720208)
I3 = (-0.069850, -0.997555, +0.002429)
I4 = (+0.024161, -0.968017, -0.249718)
```

→ **HOLD-1 · HOLD-2 가 한 번의 재최적화로 동시에 풀린다.**
→ **`INDEX_openings` 를 건드릴 필요가 없다** (§3 지시 유지 가능).
→ 대가는 F2 대비 **최대 편차 16.46° → 17.21° (+0.75°)** 와
   **`#finger_switch_front_lip` 1.5 → 2.3 mm** 뿐이다.

### (참고) 개구부를 고치는 안 — 채택 불필요

당초 후보였던 "캡 포켓 아래 국소 릴리프 추가"는 위 재최적화로 **불필요해졌다.**
개구부·캡 외형은 그대로 둔다.

---

## 5. 현재 문서 상태 (이번 실행 종료 시점)

| 항목 | 상태 |
|---|---|
| 체크포인트 | `F2_rebuild_start` (`1bbe0311bfa8ecdc32a4a06d`) |
| solid body | 18개 (원본 14 + INDEX 캡 4) |
| `JaD` / `JfD` | 정상, 각 1 body, split 0 |
| 원본 엄지 파트 10개 | 무변화 |
| assembly | Joystick 25/25, dangling 참조 0 |
| INDEX holder 4개 | **F2 축으로 생성됨** (시트 6.4×6.4 정확) |
| front trim | 4개 전부 적용 (외피 돌출·캡공간 침범 해소) |
| 개별 retainer plug | **형상 제거 완료** (피처는 no-op 스텁으로 잔존) |
| MIDDLE | 미착수 |
| 공용 retainer | 미착수 |

### 남은 정리 항목 (`/features` GET 429 해제 후)

1. 트리 변수 `#finger_switch_front_lip` 을 1.5 로 바꾸고 FS 를 `getVariable` 로 되돌린다
2. `RETAINER` stage no-op 스텁 4개를 이름 확인 후 삭제
3. `GROOVE` → front trim 으로 전용한 피처 4개의 이름을 `DEBUG_I*_front_trim` 으로 변경
4. `Part 13~16` 을 `INDEX_BTN_n_cap` 으로 개명

---

## 6. L / M

### L. shared retainer 진행 가능 여부 — **가능. 단 평판이 아니라 "pad 개별 설계 1장"**

스위치 뒷면(축깊이 10.5) 실측:

| | 뒷면 중심 (x, y, z) | 법선 |
|---|---|---|
| I1 | (−13.68, −12.24, +12.10) | (−0.814, −0.500, −0.295) |
| I2 | (−11.70, −20.18, +16.46) | (−0.407, −0.575, −0.710) |
| I3 | (−4.71, −18.86, +9.14) | (−0.075, −0.997, −0.014) |
| I4 | (+5.09, −19.29, +12.07) | (+0.038, −0.956, −0.292) |

뒷면끼리 사잇각: **I1-I2 34.1° / I2-I3 52.2° / I1-I3 55.7°** / I3-I4 17.5°

세 뒷면 중심을 지나는 평면의 법선은 각 축과 **24.3° / 11.5° / 56.7°** 를 이룬다.
→ **평평한 판으로 세 뒷면을 직각으로 누를 수 없다.**
→ **1장짜리 plate + 접촉 pad 3개를 각각 다른 높이·각도로** 설계해야 한다 (사용자 §15 예상과 일치).

I4 뒷면 중심은 그 평면에서 **7.35 mm** 떨어져 있고 분할면 반대쪽 쉘이므로
**I4 는 별도 소형 retainer** 가 자연스럽다 (§15 안 A).

후면 접근은 확보되어 있다: 홀더 후방 표본에서 쉘 벽에 매립된 지점 **0 %**.

> **단, retainer 설계는 §15 지시대로 "holder 4개가 전부 검증된 뒤"에 착수한다.**
> 지금은 HOLD-1/2 로 축이 바뀔 수 있으므로 **착수하지 않았다.**

### M. INDEX 전체 상태

| 단계 | 상태 |
|---|---|
| F2 축 반영 | **완료** |
| holder 4개 재생성 | **완료** (시트 정확, 분할 clip 적용, identity 보존) |
| front trim | **완료** |
| CLEARNBR | **완료** (폭 7.4 → 6.4 정정) |
| 개별 twist-lock 제거 | **완료** |
| exact SAT (설계 위치) | **PASS** 1.200 mm |
| exact SAT (실제 착좌) | **HOLD-1** 1.145 mm |
| 칸막이 | **HOLD-2** 0.648 mm |
| 나사 B | **HOLD-3** 2.27 mm (I4) |
| 개구부 / stem / 캡 정합 | **PASS** |
| 분할면 ownership | **PASS** |
| JaD/JfD identity · assembly | **PASS** |
| 캡 밑면 pad | 미착수 |
| 공용 retainer | 미착수 |
| MIDDLE | 미착수 |

**판정: 재생성은 성공, 승인 기준 3건 미달 → §14 지시에 따라 중단하고 보고.**

---

## 7. 다음 실행 권고 (승인 시)

한 번의 FS 편집으로 3건 전부 해소된다 — 피처 추가/삭제 불필요:

1. `IDX` 축을 §4-③ 값으로 교체
2. `LIP_F2` 1.5 → **2.3 mm**
3. `blankTo = seatTo + retT` → **`seatTo + 1.0`** (나사 B 여유 회복, HOLD-3)

그 뒤 이번과 동일한 검증 세트를 재실행한다:
exact SAT / 칸막이(포켓 기준) / 착좌 깊이 실측 / 나사 B 3D / 분할 ownership /
identity / assembly / 개구부·stem·캡 정합.

전부 통과하면 캡 밑면 pad → I1/I2/I3 공용 retaining plate → I4 별도 retainer 순으로 진행하고,
INDEX 최종 SUCCESS 이후에 MIDDLE 로 넘어간다.

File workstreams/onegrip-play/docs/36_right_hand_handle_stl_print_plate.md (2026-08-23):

# 오른손 핸들 STL 출력판 결과

## Source

- document: `a21e64f36bc61df760d4587c`
- workspace: `RIGHT_HAND_MIRROR`
- workspaceId: `db3d780eca8b1efe55a0dadd`
- Part Studio: `Joystick`
- elementId: `425d9199b59cfb1efd9ddc35`
- configuration: `default`
- source solid count: `30`

Onshape export 조건:

- binary STL
- millimeter
- fine resolution
- unique parts as individual files
- hidden parts included

## Packing policy

프로젝트 기록의 Bambu Lab P1S를 기준으로 했다.

- physical bed: `256 × 256 mm`
- reserved edge margin: `8 mm`
- packed-cell gap: `10 mm`
- 실제 geometry 최소 edge margin: `13 mm`
- 실제 geometry 최소 part clearance: `10 mm`

PCA, 주요 CAD 면 normal, world axis 후보를 비교해 각 파트를 낮고 안정적인 방향으로 눕혔다. 후보 중 최대 bed-contact area의 20% 이상을 확보하는 방향만 사용해 단순 최소 높이만 선택하는 오류를 막았다.

## Result

- build plates: `1`
- parts on plate: `30`
- disconnected STL components: `30`
- added/removed parts: `0 / 0`
- plate triangle count: `165,612`
- combined STL size: `8,280,684 bytes`
- combined STL SHA-256: `9DF047B3E161A1F1E1FBC990F88FEE9ADFE325784553F4A68F5F15F4FAF3F6C4`
- plate geometry bbox:
  - min: `[13.000, 13.000, 0.000] mm`
  - max: `[237.103, 233.091, 38.759] mm`
- overlap: `0`
- bed-boundary violations: `0`
- minimum-clearance violations: `0`

## Deliverables

- `exports/right_hand_handle_parts/plates/OneGrip_RightHand_Handle_plate_01_of_01.stl`
- `exports/right_hand_handle_parts/plates/OneGrip_RightHand_Handle_plate_01_layout.png`
- `exports/right_hand_handle_parts/plates/layout_manifest.json`
- `exports/right_hand_handle_parts/OneGrip_RightHand_Handle_Parts.zip`
- `exports/right_hand_handle_parts/OneGrip_RightHand_Handle_PrintSet.zip`
- `exports/right_hand_handle_parts/individual_stl/` — 30 source STL files
- `scripts/pack_right_hand_handle_stl.py`

## Verdict

- `RIGHT-HAND HANDLE STL = READY`
- `PLATE COUNT = 1`
- `PACKING SAFETY = PASS`

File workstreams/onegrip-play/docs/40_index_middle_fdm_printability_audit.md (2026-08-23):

# INDEX / MIDDLE 버튼 삽입부 FDM 출력성 감사

Date: 2026-08-21  
Scope: INDEX/MIDDLE shell-integrated button seats and supports only  
THUMB: excluded and unchanged  
CAD WRITE: 0

## 결론

현재 하우징 STL은 watertight mesh이지만, 검지·중지 버튼 삽입부를 포함한
**기능성 FDM 출력물로는 HOLD**다. 기존 `printMeshGate = PASS`는 manifold,
winding, connected-component 검사만 통과했다는 뜻이며, 적층 오버행이나
실제 switch 삽입 공차를 인증하지 않았다.

현재 한판 STL은 두 shell의 mating plane을 베드에 놓는다. 이 방향에서
I2/I3/I4 및 M2/M3/M4의 seat/support axis가 build vertical로부터 45°를 넘고,
특히 I3/I4 및 M3/M4는 거의 수평인 하향면을 가진다.

## 버튼별 결과

| button | owner | center build height (mm) | axis tilt from build vertical | near-horizontal downward area (mm²) | support-free functional print |
|---|---|---:|---:|---:|---|
| I1 | JfD | 22.224 | 32.0° | 9.3 | MARGINAL |
| I2 | JfD | 15.970 | 67.2° | 8.5 | HOLD |
| I3 | JfD | 5.496 | 86.1° | 179.3 | HOLD |
| I4 | JaD | 5.496 | 88.6° | 149.9 | HOLD |
| M1 | JfD | 19.835 | 33.1° | 26.7 | MARGINAL |
| M2 | JfD | 12.899 | 53.0° | 7.3 | HOLD |
| M3 | JfD | 3.538 | 71.3° | 134.8 | HOLD |
| M4 | JaD | 7.444 | 77.0° | 109.3 | HOLD |

JfD 외피에 몰려 있는 3개 그룹을 기준으로 보면 I1/M1은 형상 자체가 생성될
가능성은 있으나, I2/M2부터 support-free 신뢰성이 낮고 I3/M3는 베드 가까이에서
수평 seat/support 형상이 형성되어 가장 실패 가능성이 높다.

## 기능 공차

- switch seat: 6.40 × 6.40 mm
- conservative body envelope: 6.18 × 6.12 mm
- conservative side clearance: 0.11 / 0.14 mm per side
- physical sample 6.12 × 6.05 mm 기준: 0.14 / 0.175 mm per side
- 6.4/6.5/6.6/6.7 mm pocket coupon: 아직 미검증

수평 천장의 bridge sag, support 접촉흔적, XY 수축 또는 elephant foot 중 하나만
발생해도 0.11–0.175 mm side clearance를 소비한다. 따라서 shell이 출력되더라도
실제 ITS-1105 body가 삽입되거나 반복 탈착된다는 보장은 없다.

## 최소 구조

| item | minimum | FDM interpretation with 0.4 mm nozzle |
|---|---:|---|
| INDEX divider | 0.807 mm | 약 2 line, 경계 |
| INDEX terminal web | 1.553 mm | 약 3–4 line |
| MIDDLE ring annulus | 0.80 mm | 약 2 line, 경계 |
| MIDDLE side beam | 0.80 mm | 약 2 line, snap root로는 취약 |
| MIDDLE hook depth | 0.70 mm | 2 line 미만 가능, 파손 위험 |
| MIDDLE divider | 1.042 mm | 약 2–3 line |

INDEX는 rear가 열려 있어 support 제거 접근은 상대적으로 낫다. MIDDLE은 rear
beam/hook가 shell에 통합돼 있어 support가 생성되면 제거 과정에서 0.8/0.7 mm
구조를 손상하거나 seat 내부를 거칠게 만들 가능성이 높다.

## 판정

- shell mesh/manifold: PASS
- 외형 크기 확인용 하우징 mock-up: CONDITIONAL
- 현재 방향의 support-free 출력: HOLD
- ITS-1105 실제 삽입/작동용 출력: HOLD
- THUMB 변경 필요: 없음

## 다음 CAD 단계 권고

1. THUMB geometry는 유지한다.
2. INDEX/MIDDLE seat ceiling을 45° chamfer 또는 self-supporting 형상으로 바꾼다.
3. MIDDLE 0.8 mm beam/ring과 0.7 mm hook root를 FDM용으로 보강하거나,
   holder를 shell과 분리된 삽입형 carrier로 만든다.
4. full shell보다 먼저 6.4/6.5/6.6/6.7 mm pocket coupon을 출력해 실제 lot과
   filament별 삽입 공차를 확정한다.
5. 최종 출력 STL에는 기능 seat 내부 support가 생기지 않는 방향 또는 분할 구조를
   적용하고, slicer layer preview에서 floating island와 bridge를 재검사한다.

Numeric data: `cad_dump/index_middle_printability_audit.json`

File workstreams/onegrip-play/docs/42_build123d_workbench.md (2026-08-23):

# build123d 작업 환경

날짜: 2026-08-21  
기준 CAD: `FINGER_SIMPLIFIED_CARRIER_V1`  
Onshape versionId: `f51e9d9a868db9ef0fcd4b06`

## 목적

Onshape의 확정 형상을 임의로 추정해 다시 그리는 환경이 아니라, 확정된
I1~I4/M1~M4 중심·축과 RWID/RZKD 캐리어 치수를 로컬 파라메트릭 코드의
고정 기준으로 사용한다.

## 환경

- Python: `3.12`
- build123d: `0.11.1`
- 가상환경: `.venv-build123d`
- 코드: `build123d_workbench/`
- 생성물: `build123d_workbench/out/` (Git 제외)

설치 및 전체 검증:

```powershell
.\scripts\setup_build123d.ps1
```

STEP/STL만 다시 생성:

```powershell
.\.venv-build123d\Scripts\python.exe -m build123d_workbench.export_baseline
```

스모크 테스트:

```powershell
.\.venv-build123d\Scripts\python.exe -m build123d_workbench.smoke_test
```

MIDDLE 신규 설계/검증/렌더/출력 배치:

```powershell
.\.venv-build123d\Scripts\python.exe -m build123d_workbench.validate_middle_redesign
.\.venv-build123d\Scripts\python.exe -m build123d_workbench.render_middle_redesign
.\.venv-build123d\Scripts\python.exe -m build123d_workbench.prepare_middle_print_stl
```

`middle_redesign.py` 상단에 switch/pocket/cap/opening/exposure, M1~M4 datum,
carrier wall, terminal/wiring clearance를 모았다. 신규 캐리어 OCC B-rep은
`validate_middle_redesign.py`에서 고정 INDEX/RWID/RZKD mesh obstacle과 함께
검사하며, 모든 스크립트의 Onshape CAD WRITE는 0건이다.

## 모델 경계

현재 build123d 네이티브 B-rep으로 이식한 범위는 단순 공용 캐리어의 신규
재료다.

- JfD/RWID 측: I1~I3 포스트 3, M1~M3 포스트 3, 백본 4
- JaD/RZKD 측: I4 포스트 1, M4 포스트 1, 백본 1
- 합계: 13 solid

기존 JaD/JfD 쉘과 RWID/RZKD STL은 위치·외형 참고용 mesh source로만
연결한다. STL triangulation을 editable B-rep으로 오인하지 않으며, manifest에
각 원본의 SHA-256을 기록한다. 쉘/리테이너를 수정할 다음 단계에서는 현재
Onshape version에서 STEP 또는 Parasolid를 직접 내보내 B-rep source로 추가해야
한다.

## 이어서 작업할 위치

- 확정 좌표/치수: `build123d_workbench/source_of_truth.py`
- 캐리어 형상 함수: `build123d_workbench/model.py`
- 출력/manifest: `build123d_workbench/export_baseline.py`
- 회귀 검사: `build123d_workbench/smoke_test.py`

확정 기준을 보존하려면 `source_of_truth.py`를 직접 덮어쓰지 않고, 신규 설계
모듈에서 해당 값을 import한 뒤 파생 파라미터로 실험한다.

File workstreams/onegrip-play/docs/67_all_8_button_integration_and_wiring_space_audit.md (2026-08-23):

# 67 — All 8 Button Integration and Wiring-Space Audit

## 1. 결론

8개 승인 버튼과 5개 carrier service group을 **서로 union하지 않은 원래 생산 의도 좌표**에서 감사했다. 생산 형상 수정, carrier cut, wire solid, full shell boolean, assembly STEP/STL export는 수행하지 않았다.

- ALL 8 MECHANICAL BASELINES = **PRESERVED**
- HW504-A / HW504-B = **REFERENCE / PLACEHOLDER GEOMETRY**
- HW504-DEPENDENT RESULTS = **PROVISIONAL — ACTUAL JOYSTICK REQUIRED**
- SZH-EK056 EXACT GEOMETRY = **NEEDS PHYSICAL MEASUREMENT**
- CARRIER-TO-CARRIER INTEGRATION = **PASS**
- CARRIER-CARRIER PENETRATION = **0.000000000 mm³ max**
- MIN INTER-CARRIER CLEARANCE = **0.104805 mm**
- SWITCH / TERMINAL CROSS-COLLISION = **HOLD — M4 T2 ↔ N3 T3; HW504 findings provisional**
- ALL-8 MOTION ENVELOPE = **PASS**
- ALL-8 FULL PENETRATION = **0.000000000 mm³**
- SERVICEABILITY = **PASS**
- TERMINAL ACCESS = **HOLD — M4/N3 terminal interface; N1/N2 vs HW504 provisional**
- WIRING SPACE = **PROVISIONAL — ACTUAL JOYSTICK REQUIRED**
- RECOMMENDED ELECTRICAL TOPOLOGY = **8 signals + common GND**
- RECOMMENDED GROUND STRATEGY = **2-button carrier-local daisy-chain + five service-group returns**
- RECOMMENDED WIRING TRUNK = **split JaD/JfD half-trunks**
- FASTENING SPACE = **TIGHT**
- EXTERIOR = **PRESERVED**
- PEAK PYTHON RSS = **534.7 MB**
- OVERALL = **HOLD — THIS INTEGRATION INTERFACE NEEDS REDESIGN (M4 T2 ↔ N3 T3)**

## 2. Freeze / 방법

docs/62~66의 cap, switch, guide, hard stop, rear support, functional carrier geometry 및 exterior를 read-only 입력으로 사용했다. 5개 carrier, 8개 cap STEP와 승인 JSON/MD의 SHA-256를 작업 전후 비교했다. Exact 계산은 단일 Python process와 단일 OCC operation 흐름으로 실행했다. AABB가 분리된 쌍은 penetration이 불가능하므로 보수적 분리 하한으로 screen했고, 겹치거나 가까운 쌍만 serial OCCT exact를 실행했다.

HW504-A/B는 최종 구매품이 아니라 **REFERENCE / PLACEHOLDER GEOMETRY**다. 따라서 N2 body/T1/T2↔HW504-A, N1/N2 wiring↔HW504 및 모든 carrier↔HW504 clearance는 **PROVISIONAL — ACTUAL JOYSTICK REQUIRED**로 재분류했다. 이 값들은 Finger/N1/N2 production geometry 수정 근거로 사용하지 않는다.

HW504와 무관한 승인 회귀 reference(I2/I3 FULL cap gap 2.14 mm 이상, M4/N3 minimum cap gap 3.132654 mm, I4↔I3 3.248773 mm, M3↔M4 4.847042 mm, critical wall 1.20 mm 이상)는 입력 STEP/JSON 해시 무변경과 production geometry edit 0으로 보존됐다.

## 3. Carrier-to-carrier exact 10쌍

| pair | exact distance mm | penetration mm³ | gate |
|---|---:|---:|---|
| N1_N2<->I2_I3 | 7.127319 | 0.000000000 | PASS |
| N1_N2<->M4_N3 | 31.010128 | 0.000000000 | PASS |
| N1_N2<->I4 | 8.845497 | 0.000000000 | PASS |
| N1_N2<->M3 | 30.533602 | 0.000000000 | PASS |
| I2_I3<->M4_N3 | 12.373789 | 0.000000000 | PASS |
| I2_I3<->I4 | 0.104805 | 0.000000000 | PASS |
| I2_I3<->M3 | 12.216827 | 0.000000000 | PASS |
| M4_N3<->I4 | 12.121880 | 0.000000000 | PASS |
| M4_N3<->M3 | 0.400000 | 0.000000000 | PASS |
| I4<->M3 | 12.385517 | 0.000000000 | PASS |

최접 interface는 **I2_I3<->I4**, exact distance **0.104805 mm**다. Carrier penetration이 발생하면 `THIS INTEGRATION INTERFACE FAILED`로 판정하도록 했으며, 이번 carrier 결과는 **PASS**다.

## 4. Switch / terminal cross audit

- total checked rows: **1078**
- serial OCCT exact rows: **73**
- conservative AABB-separated rows: **1005**
- failed cross interfaces: **4**

| interface | penetration mm³ | method | production classification |
|---|---:|---|---|
| N2 body<->HW504_A | 0.015188570 | OCCT_EXACT | PROVISIONAL — ACTUAL JOYSTICK REQUIRED |
| N2.T1<->HW504_A | 0.031265583 | OCCT_EXACT | PROVISIONAL — ACTUAL JOYSTICK REQUIRED |
| N2.T2<->HW504_A | 0.021290636 | OCCT_EXACT | PROVISIONAL — ACTUAL JOYSTICK REQUIRED |
| M4.T2<->N3.T3 | 0.283393028 | OCCT_EXACT | HW504-INDEPENDENT / VALID INTEGRATION FINDING |

HW504와 무관한 유효 integration failure는 **M4 T2 ↔ N3 T3 = 0.283393028 mm³** 한 건이다. 이는 `THIS INTEGRATION INTERFACE NEEDS REDESIGN`이지만 8-button exterior 불가 판정은 아니다. 나머지 HW504 관련 세 건은 실제 SZH-EK056 측정 전 production failure로 세지 않는다. N1 terminal 4개와 N2 T1/T3 active + T2/T4 trimmed conditional 상태는 그대로이며 새 trim/bend는 없다.

## 5. Motion envelope

| state | FULL buttons | verdict | failed interface count |
|---|---|---|---:|
| ALL_REST | - | PASS | 0 |
| N1_FULL | N1 | PASS | 0 |
| N2_FULL | N2 | PASS | 0 |
| I2_FULL | I2 | PASS | 0 |
| I3_FULL | I3 | PASS | 0 |
| I4_FULL | I4 | PASS | 0 |
| M3_FULL | M3 | PASS | 0 |
| M4_FULL | M4 | PASS | 0 |
| N3_FULL | N3 | PASS | 0 |
| I2_I3_FULL | I2, I3 | PASS | 0 |
| M4_N3_FULL | M4, N3 | PASS | 0 |
| I4_I3_FULL | I3, I4 | PASS | 0 |
| M3_M4_FULL | M3, M4 | PASS | 0 |
| N1_N2_FULL | N1, N2 | PASS | 0 |
| ALL_8_FULL | I2, I3, I4, M3, M4, N1, N2, N3 | PASS | 0 |

각 FULL은 0.350 mm다. Own cap-guide/actuator/hard-stop contact는 intentional이고 docs/62~66 exact baseline을 그대로 상속한다. 본 감사에서는 cap ↔ foreign carrier/switch 및 cap ↔ cap을 분리해 unintended penetration만 판정했다.

## 6. Service path

| service group | direction | translation mm | rotation deg | verdict |
|---|---|---:|---:|---|
| N1_N2 | [-1.0, 0.0, 0.0] | 15.0 | 0.0 | PASS |
| I2_I3 | [-1.0, 0.0, 0.0] | 15.0 | 0.0 | PASS |
| M4_N3 | [1.0, 0.0, 0.0] | 15.0 | 0.0 | PASS |
| I4 | [1.0, 0.0, 0.0] | 15.0 | 0.0 | PASS |
| M3 | [-1.0, 0.0, 0.0] | 15.0 | 0.0 | PASS |

기본 순서는 `shell open → 해당 carrier group release → 해당 group switch service`다. I4/M3는 각 standalone carrier를 먼저 빼고 ITS를 서비스한다. 다른 carrier를 먼저 제거해야 하는 종속성은 만들지 않는 것을 기준으로 했다.

## 7. Wiring-space / terminals

| button | usable terminals | trimmed | solder access | bend/tool keepout |
|---|---|---|---|---|
| N1 | T1, T2, T3, T4 | - | PROVISIONAL — ACTUAL JOYSTICK REQUIRED | PROVISIONAL — ACTUAL JOYSTICK REQUIRED |
| N2 | T1, T3 | T2, T4 | PROVISIONAL — ACTUAL JOYSTICK REQUIRED | PROVISIONAL — ACTUAL JOYSTICK REQUIRED |
| I2 | T1, T2, T3, T4 | - | TIGHT | TIGHT |
| I3 | T1, T2, T3, T4 | - | TIGHT | TIGHT |
| I4 | T1, T2, T3, T4 | - | TIGHT | TIGHT |
| M3 | T1, T2, T3, T4 | - | TIGHT | TIGHT |
| M4 | T1, T2, T3, T4 | - | TIGHT | TIGHT |
| N3 | T1, T2, T3, T4 | - | TIGHT | TIGHT |

전기 baseline은 GPIO가 충분할 때 **8 independent signals + common GND**를 추천한다. 물리 harness는 shared two-button carrier 내부에서만 local ground daisy-chain하고, I4/M3는 독립 return을 유지한 뒤 5개 service-group return을 후단에서 합치는 안을 추천한다. 8개 전체 ground chain은 service dependency 때문에 추천하지 않는다.

Wire OD **1.0~1.3 mm**는 공간 seed일 뿐이며 최종 AWG가 아니다. 기존 HW504 placeholder에 대한 N1/N2 BLOCKED 판정은 **PROVISIONAL — ACTUAL JOYSTICK REQUIRED**다. Candidate 2 **split JaD/JfD half-trunks**를 개념 기준안으로 유지하지만, 실제 SZH-EK056 측정 전 production wiring clearance는 확정하지 않는다. Carrier cut과 wire solid는 없다.

## 8. SZH-EK056 actual-part measurement checklist

로컬 workspace에는 SZH-EK056 전용 controlled drawing, exact STEP 또는 실물 측정 registry가 없다. docs/55의 `34.5 × 26 × 38 mm` 판매처 envelope와 유사 모듈 문서의 `34.0 × 26.3 × 1.6 mm` PCB/Ø3 mm 홀은 참고용 nominal일 뿐 생산 CAD datum이 아니다. 판정은 **NEEDS PHYSICAL MEASUREMENT**다.

먼저 PCB top plane, 두 직교 PCB edge, neutral shaft axis를 측정 datum으로 지정하고 다음을 기록한다.

| # | measurement | method / datum | record required |
|---:|---|---|---|
| 1 | PCB X / Y / Z | caliper; PCB edge-to-edge and board thickness | length, width, thickness; max/min across samples |
| 2 | mounting-hole X/Y pitch | hole-center coordinates from selected PCB corner datum | all four X/Y coordinates and opposite/diagonal pitches |
| 3 | mounting-hole diameter | pin gauges or caliper; distinguish plating/countersink | diameter of each hole |
| 4 | joystick center relative to PCB | neutral shaft axis to both PCB edges and hole pattern | center X/Y and concentricity/offset |
| 5 | X potentiometer envelope | axis-aligned bbox from PCB datums | min/max X/Y/Z, housing center, tabs/lead protrusions |
| 6 | Y potentiometer envelope | axis-aligned bbox from PCB datums | min/max X/Y/Z, housing center, tabs/lead protrusions |
| 7 | bottom push-switch envelope | bottom-view bbox and shaft-axis relation | min/max X/Y/Z, body/lead protrusion, push travel |
| 8 | shaft / pivot height | PCB top plane to pivot center and neutral shaft endpoints | pivot Z, exposed shaft length, cap interface diameter/shape |
| 9 | connector envelope | PCB datum bbox | header X/Y/Z, pin pitch, orientation, mating-plug projection |
| 10 | maximum moving envelope | sweep at max ±X, ±Y, diagonal tilt and axial push | union bbox/radial envelope including shaft and intended knob |

권장 기록에는 측정 sample 수, 보드 revision/실크, 판매처/lot, 정면·측면·하부 사진과 측정 공구 분해능도 포함한다. Moving envelope는 cap/knob을 포함한 최대 X/Y tilt와 axial push 전후 모두 측정한다.

## 9. Fastening-space audit

| group | owner | shell-side area | access | reason |
|---|---|---|---|---|
| N1_N2 | JfD | TIGHT | TIGHT | frozen N1/N2 service corridor remains tight; the HW504-adjacency portion is PROVISIONAL — ACTUAL JOYSTICK REQUIRED |
| I2_I3 | JfD | AVAILABLE | AVAILABLE | shared carrier has broad shell-side rail area, subject to future boss verification |
| M4_N3 | JaD | AVAILABLE | AVAILABLE | shared carrier has broad shell-side rail area, subject to future boss verification |
| I4 | JaD | AVAILABLE | AVAILABLE | standalone carrier has a direct shell-open approach, subject to future boss verification |
| M3 | JfD | AVAILABLE | AVAILABLE | standalone carrier has a direct shell-open approach, subject to future boss verification |

Fastener, boss, captured nut, heat-set insert는 모델링하지 않았다. 이 결과는 shell-side 면적/접근 방향의 다음 단계 가능성 감사이며, 전체 판정은 **TIGHT**다.

## 10. Required renders

1. `renders/all_8_button_integration_wiring_space_audit/01_all_8_caps_exterior_overview.png`
2. `renders/all_8_button_integration_wiring_space_audit/02_transparent_all_8_internal.png`
3. `renders/all_8_button_integration_wiring_space_audit/03_isolated_color_coded_carrier_groups.png`
4. `renders/all_8_button_integration_wiring_space_audit/04_carrier_closest_interfaces.png`
5. `renders/all_8_button_integration_wiring_space_audit/05_switches_and_terminals_only.png`
6. `renders/all_8_button_integration_wiring_space_audit/06_thumb_hw504_vs_finger_internals.png`
7. `renders/all_8_button_integration_wiring_space_audit/07_service_removal_directions.png`
8. `renders/all_8_button_integration_wiring_space_audit/08_wire_departure_arrows.png`
9. `renders/all_8_button_integration_wiring_space_audit/09_candidate_wiring_trunks.png`
10. `renders/all_8_button_integration_wiring_space_audit/10_all_8_full_envelope.png`
11. `renders/all_8_button_integration_wiring_space_audit/11_n1_n2_terminal_hw504_conditionals.png`

Render 06/09/11의 HW504 형상과 수치는 모두 placeholder reference visualization이다.

## 11. STOP

production assembly, wire solid, fastening feature, MCU/PCB, full shell, STL/print plate 단계로 자동 확장하지 않는다. 사용자 검토를 받고 STOP한다.

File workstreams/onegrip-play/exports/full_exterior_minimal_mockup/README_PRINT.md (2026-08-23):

# OneGrip Current Main — exterior handling mockup

Source of truth:

- Onshape document: `OneGrip_Play_V1`
- workspace: `Main`
- Part Studio: `Joystick`
- state: current Stage-D export
- source archive: `Joystick_Current_Main_StageD.zip`
- source solids: 30 STL files

No cached shell, mirrored STL, or pre-Stage-D mesh is used.

## Files

### `OneGrip_Current_Main_Exterior_Alignment_Check.stl`

Exact alignment/reference STL. It contains the 19 currently visible exterior
solids in their original Part Studio coordinates:

- `Joystick_1`, `Joystick_2`
- `Backplate`
- eight original THUMB caps
- INDEX I1-I4 caps
- MIDDLE M1-M4 caps

No part is translated, mirrored, scaled, or otherwise modified. This file is
the position and opening/cap alignment source of truth, but its moving controls
remain separate shells.

### `OneGrip_Current_Main_Exterior_Mockup_SlicerUnion.stl`

Non-functional one-file handling mockup. It contains the exact alignment mesh
plus 20 small closed bridge cylinders:

- three cross-seam shell bridges
- one Backplate-to-shell bridge
- one hidden bridge per THUMB/INDEX/MIDDLE cap

Each bridge penetrates its target by 1.2 mm. Source parts themselves are not
moved. The STL contains overlapping closed volumes rather than a CAD B-rep
boolean union, so enable **merge/union overlapping volumes** in the slicer.

## Suggested quick print

- scale: 100%
- units: millimetres
- place the broad handle base on the build plate
- layer height: 0.20-0.28 mm
- walls: 3
- infill: 12-18%
- supports: build-plate-only if required by the selected material/printer
- enable slicer union/merge overlapping volumes

This is only an ergonomic/exterior handling mockup. Every button is immobilized
by a sacrificial bridge and is not expected to operate.

## Intentional omission

`Small_joystick_attachment` is excluded. Its STL is at a remote Part Studio
staging position (`X approximately 96.5-110.5 mm`), while the actual location is
defined by an Assembly mate that is not encoded in this Part Studio ZIP.
Guessing that transform would repeat the previous mixed-coordinate error.

Exact selected-part audit, hashes, topology, proximity sanity values, and bridge
coordinates are recorded in `mockup_manifest.json`.

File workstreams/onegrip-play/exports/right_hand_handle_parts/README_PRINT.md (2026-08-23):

# OneGrip 오른손 핸들 출력 세트

## 바로 출력할 파일

`plates/OneGrip_RightHand_Handle_plate_01_of_01.stl`

프로젝트 기록의 Bambu Lab P1S 기준으로 배치했다.

- plate: 256 × 256 mm
- 실제 모델 점유 범위: X 13.000–237.103 mm / Y 13.000–233.091 mm
- 실제 최소 가장자리 여유: 13.0 mm
- 파트 간 최소 간격: 10.0 mm
- 최대 출력 높이: 38.759 mm
- printable solids: 30
- STL disconnected components: 30
- triangle count: 165,612
- plate STL SHA-256: `9DF047B3E161A1F1E1FBC990F88FEE9ADFE325784553F4A68F5F15F4FAF3F6C4`

## 슬라이서에서

1. 단위를 `mm`로 연다.
2. plate STL을 원점 기준 그대로 불러온다.
3. `자동 배치/Auto arrange`는 실행하지 않는다. 이미 10 mm 안전 간격으로 배치돼 있다.
4. 하나의 모델로 보이더라도 STL 내부에는 서로 닿지 않는 30개 component가 있다.
5. 출력 전 슬라이스 미리보기에서 첫 레이어와 shell 내부 overhang을 확인한다.
6. 작은 spacer/cap의 첫 레이어가 불안하면 brim 3–5 mm를 추가한다.

## 구성

- `OneGrip_RightHand_Handle_Parts.zip`: Onshape 원본 개별 STL 30개
- `individual_stl/`: 압축을 푼 개별 STL
- `plates/OneGrip_RightHand_Handle_plate_01_of_01.stl`: 한 판 출력용 결합 STL
- `plates/OneGrip_RightHand_Handle_plate_01_layout.png`: 배치도
- `plates/layout_manifest.json`: 모든 파트의 방향, 위치, 치수 및 검증값
- `OneGrip_RightHand_Handle_PrintSet.zip`: 위 자료를 묶은 최종 전달 파일

다른 프린터의 베드가 256 × 256 mm보다 작으면 이 plate STL을 그대로 출력하지 말고 개별 STL을 다시 패킹해야 한다.

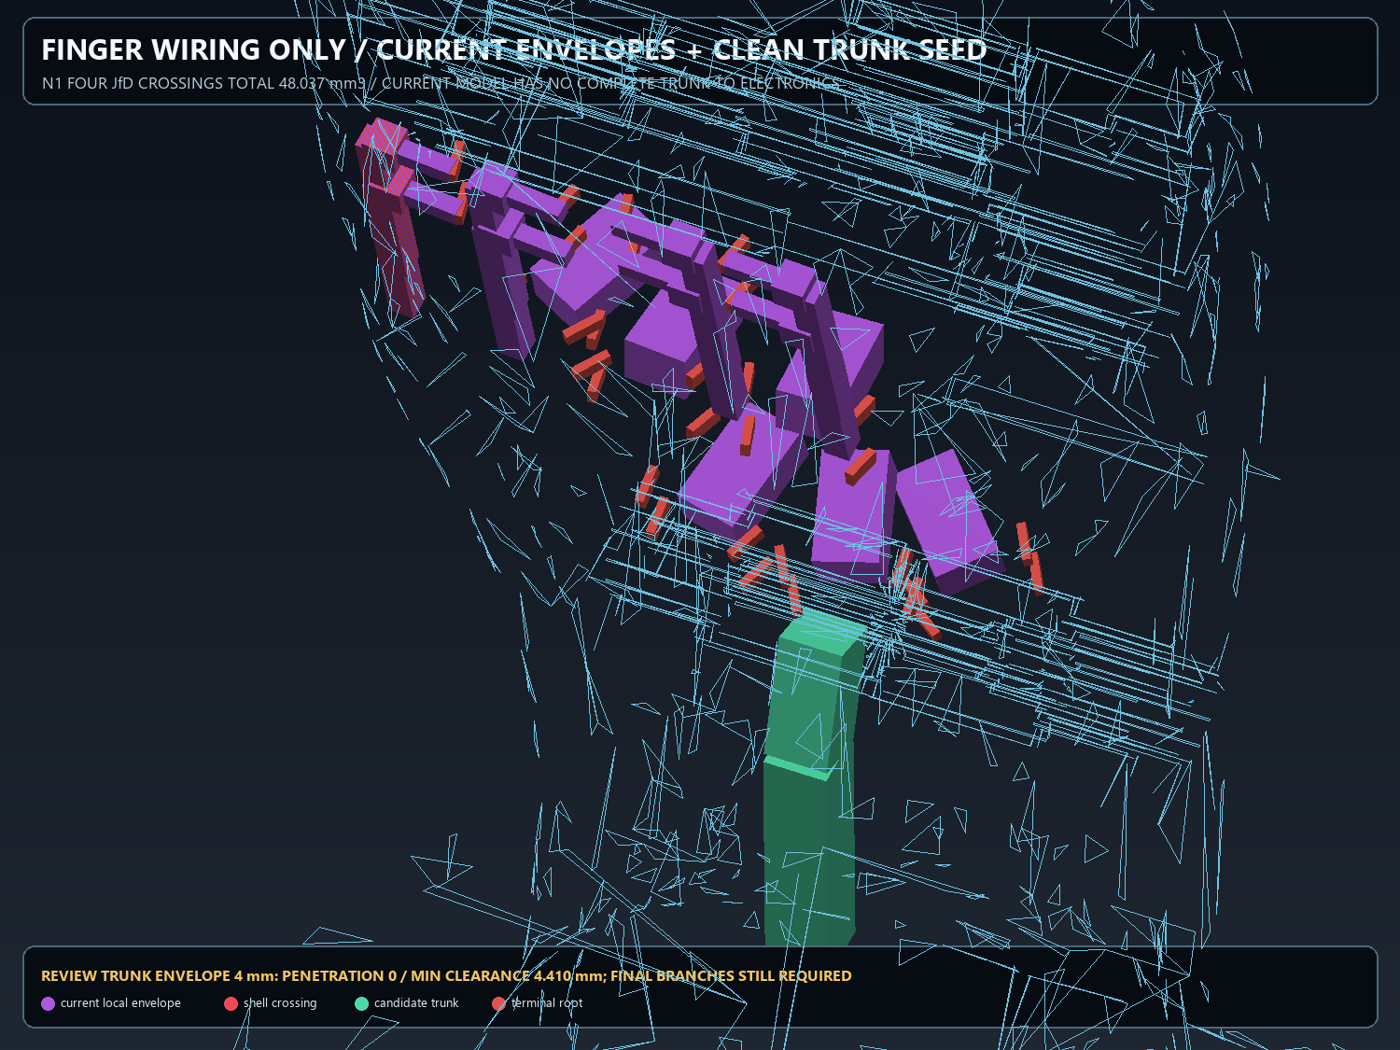
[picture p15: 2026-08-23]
workstreams/onegrip-play/renders/finger_thumb_integrated_v3_internal_review/08_finger_wiring_only.png

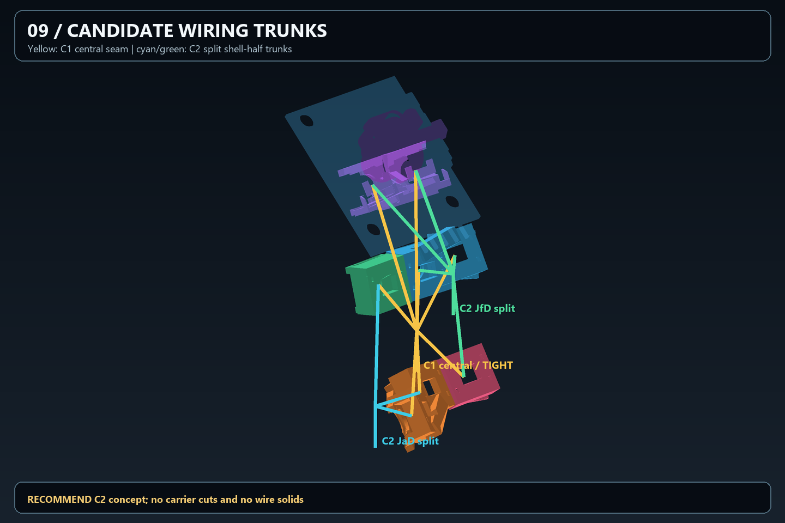
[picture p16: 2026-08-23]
workstreams/onegrip-play/renders/all_8_button_integration_wiring_space_audit/09_candidate_wiring_trunks.png

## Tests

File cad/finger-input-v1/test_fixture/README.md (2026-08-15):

# P0 단일 손가락 지그

## 목적

OneGrip 전체 그립을 출력하기 전에 손가락 하나로 LEFT/CENTER/RIGHT의 구분,
힘, 연타, 복귀를 확인하는 지그다. `fixture_base`와 `fixture_carrier`는 분리
출력하고 M4 볼트 두 개로 결합한다.

## 조절 범위

- 높이: 두 upright의 24mm 세로 슬롯
- 각도: carrier의 횡축을 기준으로 마찰 고정; 기구상 ±15° 이상, 시험은
  OneGrip 목표 범위인 ±8°부터 사용
- 카트리지 깊이: carrier의 19.4mm 전체 슬롯(볼트 중심 가동 16mm), 기준에서 ±8mm

## 출력 파일

- `petg_tolerance_coupon.stl` — 반드시 먼저 출력
- `hard_stop_shim_0.1mm.*`, `hard_stop_shim_0.2mm.*`,
  `hard_stop_shim_0.3mm.*` — 0.1/0.2mm는 치수 참고
- `hard_stop_shim_profile.dxf` — 0.1/0.2mm PET shim stock 절단용 2D 프로파일
- `fixture_base.stl`
- `fixture_carrier.stl`
- `fixture_with_middle_module.step/.3mf` — 독립 솔리드를 유지한 조립 확인 권위본,
  일체 출력 금지

개별 출력물은 위 `*.stl` 세 파일과 필요한 shim이다. 지그·중지 카트리지가
접촉한 전체 조립체는 STEP/3MF로만 배포하며 합쳐진 조립체 STL은 제공하지 않는다.

## 체결품

- M4×35 볼트 2, M4 와셔 4, M4 손잡이 너트 2
- M3×10 볼트 2, M3 너트 또는 insert 2
- 책상 고정용 M6 볼트 또는 클램프 2

## 사용 순서

1. 지그를 책상에 고정한다.
2. 가운데손가락 높이를 기준으로 carrier를 맞춘다.
3. 손목·손가락에 힘을 주지 않은 상태에서 CENTER 캡 중심에 지문 중심이
   오도록 높이와 깊이를 맞춘다.
4. 각도를 0°에서 시작해 ±3°, ±6°, ±8° 순으로 한 변수씩 바꾼다.
5. [`../../../docs/finger_module_test_protocol.md`](../../../docs/finger_module_test_protocol.md)의 P0 절차를 실행한다.

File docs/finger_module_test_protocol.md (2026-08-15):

# OneGrip Play 손가락 모듈 P0/P1/P2 정량 시험 절차

## 1. 목적과 적용 범위

이 문서는 OneGrip Play의 `LEFT / CENTER / RIGHT` 3방향 손가락 입력 구조를 감각적인 평가가 아니라 동일한 수치로 비교하기 위한 절차다.

- **P0:** 손가락 하나의 A/B/C 구조 비교와 V1 메커니즘 선택
- **P1:** 검지·중지·약지·소지 4모듈 배열, 특히 약지·소지 연동 검증
- **P2:** 버티컬 OneGrip 본체, 손바닥 지지, 스트랩, 그립 기울임을 포함한 통합 검증

목표 정확도 `95%`는 초기 공학 Gate이며 임상 성능을 뜻하지 않는다. 사용자의 운동 범위가 크게 다르므로 대상 사용자 멘토 결과는 일반 팀원 결과와 합산하지 않고 별도 열로 기록한다.

## 2. 시험 전 고정 조건

### 2.1 시제품과 출력

- 프린터, 노즐, 필라멘트, 슬라이서 프로파일을 기록한다.
- 기본 출력 조건은 PETG, 0.4mm 노즐, 0.2mm 적층이다.
- A/B/C는 같은 제조사의 같은 로트 스위치를 사용한다.
- 스위치 3개의 작동력을 장착 전 각각 5회 측정하고 평균·범위를 기록한다.
- 모든 모듈에는 스위치 과행정을 막는 독립 하드스톱을 둔다.
- 시험 전 패들 100회 길들이기를 하고 파손·끼임·복귀 실패 여부를 기록한다.

### 2.2 입력 로거

- GPIO를 최소 `1kHz`로 샘플링하거나 모든 원시 에지에 마이크로초 타임스탬프를 남긴다.
- 원시 에지와 디바운스 후 이벤트를 모두 저장한다.
- 비교 시험의 디바운스는 모든 Variant에서 동일하게 `ON 5ms / OFF 10ms stable`로 시작한다.
- 한 물리 동작에서 release 뒤 `80ms` 이내 같은 입력이 다시 발생하면 중복 입력 후보로 표시한다.
- 시험 중 알고리즘으로 다른 방향을 억지로 배제하는 상호잠금은 끈다. 구조 자체의 오입력을 먼저 측정한다.

권장 CSV 열:

```text
stage,participant,hand_size,finger,variant,trial,target,
command_time,first_raw_edge,event_time,release_time,
left_count,center_count,right_count,result,
peak_force_N,reposition,effort_1_5,discomfort_1_5,notes
```

### 2.3 용어와 계산

한 trial의 판정창은 지시 후 `500ms`다.

- **성공:** 의도 방향 이벤트가 1회 발생하고 다른 방향 이벤트가 없음
- **누락:** 500ms 안에 의도 방향 이벤트가 없음
- **이웃 우발 입력:** 의도하지 않은 두 방향 중 하나가 1회 이상 발생
- **중복 입력:** 한 번의 의도 동작에서 의도 방향이 2회 이상 디바운스 이벤트로 발생
- **동시 입력:** 서로 다른 방향의 활성 구간이 `10ms` 이상 겹침
- **반응시간:** 지시 시점부터 첫 유효 이벤트까지
- **복귀시간:** 작동 방향 release부터 세 입력이 모두 중립이 될 때까지
- **재배치:** 손끝 중심이 원래 접촉 캡/지지영역을 완전히 벗어났다가 다시 놓임

계산식:

```text
정확도(%) = 성공 trial / 전체 trial × 100
누락률(%) = 누락 trial / 전체 trial × 100
이웃 우발 입력률(%) = 이웃 입력 trial / 전체 trial × 100
중복 입력률(%) = 중복 trial / 전체 trial × 100
반복 성공률(%) = 유효 이벤트 수 / 지시 비트 수 × 100
```

한 trial에 누락과 이웃 입력이 함께 있으면 두 지표에 모두 포함하되 성공에는 포함하지 않는다.

### 2.4 피험자와 안전

- P0는 팀원 최소 3명, P1은 손 크기가 다른 최소 3명을 권장한다.
- 대상 사용자 멘토는 가능한 범위에서 P1/P2에 참여시키되 피로를 호소하면 즉시 중단한다.
- 피부 눌림, 저림, 통증, 경직 증가, 손가락이 걸려 빠지지 않는 상황이 나타나면 해당 시험을 즉시 중단한다.
- 스트랩은 한 손 또는 보조자가 즉시 풀 수 있어야 한다.
- 힘과 각도 목표는 설계용 수치이며 치료·진단 기준이 아니다.

## 3. 공차 쿠폰과 계측 준비

### 3.1 공차 쿠폰

본 모듈보다 먼저 다음 후보를 한 판에 출력한다.

| 기능 | 후보 CAD 간극 |
|---|---|
| 회전 패들 좌우 간극 | 면당 0.15 / 0.20 / 0.25 / 0.30mm |
| 슬라이더 간극 | 면당 0.15 / 0.20 / 0.25 / 0.30mm |
| Ø2mm 축 구멍 | 2.20 / 2.25 / 2.30 / 2.35mm |
| 스위치 포켓 | 실측 외형 +0.10 / +0.15 / +0.20mm(면당) |

선택 조건은 조립도 쉽지만 눈에 띄는 측면 흔들림 없이 100회 완전 복귀하는 가장 작은 간극이다. 선택값과 실제 출력 치수는 캘리퍼로 기록한다.

### 3.2 필요한 계측물

- 0.01mm 표시 캘리퍼
- 0~2N 범위를 읽을 수 있는 푸시풀 게이지 또는 0.01kg 분해능 저울 지그
- 스마트폰 120fps 이상 슬로모션 촬영
- 입력 로거와 PC
- 손가락 위치 표시용 2mm 점 스티커
- 0.1mm·0.2mm·0.3mm 조절 심
- 육안 검사 확대경

힘은 손끝 실제 접촉점과 실제 작동 방향에서 측정한다. 스위치 플런저를 직접 눌러 얻은 힘을 손끝 작동력으로 기록하지 않는다.

## 4. P0 — 한 손가락 A/B/C 비교

### 4.1 제작 범위

1. 높이·각도 조절이 가능한 책상 고정 지그 1개
2. A/B/C 검지용 카트리지 각 1개
3. A/B 중 우선 두 안의 소지용 캡·레버 프리셋
4. 같은 스위치 로트의 스위치 9개 이상
5. 교체식 `0.1/0.2/0.3mm` 프리로드 심

Variant마다 색만 다르게 하고 로고나 이름은 가려 피험자가 선호 구조를 추측하지 않게 한다. 시험 순서는 참여자마다 `ABC / BCA / CAB`로 바꾼다.

### 4.2 기계 검사

각 Variant에서 다음을 먼저 측정한다.

| 항목 | 측정 횟수 | P0 목표 |
|---|---:|---:|
| LEFT/CENTER/RIGHT 손끝 작동력 | 각 5회 | 검지·중지 0.45~0.70N, 약지 0.40~0.65N, 소지 0.35~0.55N |
| 작동 전 손끝 이동량 | 각 5회 | CENTER 0.6~0.9mm, 측면 1.0~1.5mm |
| 완전 복귀시간 | 각 10회 | 중앙값 ≤100ms, 최대 ≤150ms |
| 패들 측면 유격 | 3점 측정 | 손끝 환산 ≤0.30mm |
| 하드스톱 뒤 추가 플런저 이동 | 각 방향 | 데이터시트 허용 과행정 이내, 구조하중은 셸이 받음 |

손을 올려놓은 중립 상태에서 60초 동안 이벤트가 한 번이라도 발생하면 프리로드 또는 지지면을 수정한 뒤 다시 시작한다.

### 4.3 단일 입력 시험

1. 참여자가 편한 높이와 각도로 지그를 맞춘다.
2. 방향별 10회 연습한다. 연습 데이터는 제외한다.
3. 화면 또는 음성 지시에 따라 LEFT/CENTER/RIGHT를 무작위로 각 30회, 총 90회 입력한다.
4. 각 지시 간격은 1.0~1.5초 무작위로 한다.
5. 손끝 점 스티커를 정면 촬영해 재배치와 측면 이동을 확인한다.
6. Variant 종료 후 effort와 discomfort를 각각 1~5로 평가한다.

**P0 단일 입력 Gate**

- 전체 정확도 `≥95%`
- 각 방향 정확도 `≥93%`
- 이웃 우발 입력률 `≤2%`
- 동시 입력률 `≤1%`
- 중복 입력률 `≤1%`
- 재배치 `≤1회/90 trial`
- effort·discomfort 중앙값 각각 `≤2/5`

### 4.4 반복 입력 시험

메트로놈에 맞춰 다음을 수행한다.

| 방향 | 속도 | 시간 | 목표 입력 수 |
|---|---:|---:|---:|
| CENTER | 4Hz | 10초 × 3세트 | 세트당 40 |
| LEFT | 3Hz | 10초 × 3세트 | 세트당 30 |
| RIGHT | 3Hz | 10초 × 3세트 | 세트당 30 |

세트 사이 30초 쉬고 방향 사이 60초 쉰다.

**P0 반복 Gate**

- 반복 성공률 `≥95%`
- 의도하지 않은 방향 `≤2%`
- 한 세트 안에서 stuck-on `0회`
- 첫 세트 대비 마지막 세트 성공률 감소 `≤5%p`
- 시험 뒤 패들 완전 복귀 실패 `0회/100회 수동 확인`

### 4.5 소지 확인

P0 점수 상위 두 Variant를 소지 프리셋으로 바꿔 방향별 20회와 2Hz 10초 반복시험을 한다.

- 초기 소지 정확도 `≥93%`
- 이웃 우발 입력률 `≤3%`
- 작동력 `0.35~0.55N`
- 지지면에 올려둔 소지 무게로 자동 작동하지 않음
- 소지를 누를 때 약지 surrogate 또는 실제 약지의 동반 접촉을 영상으로 기록

소지 Gate를 통과하지 못한 구조는 검지 점수가 높아도 V1으로 바로 복제하지 않는다.

### 4.6 내구 예비시험

선정 후보 1개에 방향별 500회, 총 1,500회 자동 또는 수동 반복을 가한다.

- 파손·축 이탈·스위치 이동 0회
- 전후 작동력 변화 `≤15%`
- 전후 손끝 유격 증가 `≤0.15mm`
- 정확도 재시험 10회/방향에서 `≥95%`

### 4.7 P0 선택 규칙

1. 안전 중단 또는 소지 Gate 실패 구조는 제외한다.
2. 필수 Gate 통과 구조끼리 `finger_module_tradeoff.md` 점수를 실측값으로 갱신한다.
3. 정확도 차이가 2%p 이내면 손끝 재배치가 적고 소지 점수가 높은 구조를 고른다.
4. B가 통과하면 B를 우선한다.
5. B가 실패하고 A가 통과하면 A를 V1으로 고른다.
6. C는 A와 B보다 정확도가 최소 3%p 높지 않으면 공차 위험 때문에 선택하지 않는다.

## 5. P1 — 네 손가락 배열

### 5.1 제작 범위

- 선택 구조의 검지·중지·약지·소지 카트리지 각 1개
- 손가락 중심 위치 `116 / 86 / 57 / 30mm`를 시작값으로 하는 배열 지그
- 각 모듈 전후 `±8mm`, 회전 `±8°` 조절부
- 손가락 길이와 폭이 다른 캡 프리셋
- 손바닥 하중을 받되 실제 기기 기울임은 없는 고정 그립 더미

### 5.2 맞춤 절차

1. 사용자가 힘을 주지 않고 그립을 잡는다.
2. 중지를 먼저 맞추고 검지, 약지, 소지 순으로 전후 위치를 맞춘다.
3. 손가락 지문 중심이 CENTER 캡 중심에서 `±2mm` 안인지 확인한다.
4. 손톱·DIP 관절·손가락 옆면이 하드 셸 모서리에 닿지 않는지 확인한다.
5. 중립 60초 동안 자동 입력이 없도록 프리로드를 조정한다.
6. 최종 슬롯 위치, 각도, 캡 규격을 사진과 mm로 기록한다.

맞춤시간 목표는 첫 사용자 `≤15분`, 같은 프리셋 재조립 `≤5분`이다.

### 5.3 12방향 무작위 시험

각 참여자는 12개 입력을 각 30회, 총 360회 수행한다. 120회마다 2분 쉰다.

**P1 Gate**

- 12방향 전체 정확도 `≥95%`
- 각 손가락 정확도 `≥93%`
- 약지·소지 각각 P1 수정 후 `≥95%` 목표
- 이웃 방향 우발 입력률 전체 `≤2%`
- 다른 손가락의 우발 입력률 `≤2%`
- 동시 입력률 `≤1%`
- 손끝 재배치 `≤4회/360 trial`

### 5.4 finger-enslaving 교차시험

다음 쌍을 번갈아 각 20회 수행한다.

- 검지 CENTER ↔ 중지 CENTER
- 중지 LEFT ↔ 약지 RIGHT
- 약지 CENTER ↔ 소지 CENTER
- 약지 LEFT ↔ 소지 RIGHT
- 소지 LEFT ↔ 소지 RIGHT

한 방향을 누른 상태에서 다른 손가락을 10회 누르는 chord 시험도 한다. 단, 같은 손가락의 LEFT와 RIGHT 동시입력은 요구하지 않는다.

**교차시험 Gate**

- 지시하지 않은 손가락 이벤트 `≤3%`
- 약지·소지 쌍에서 `≤5%`면 형상 수정 후 1회 재시험 허용
- 손가락이 지지홈 밖으로 빠짐 `0회`
- 한 키를 누른 상태에서도 이웃 손가락 입력 성공률 `≥90%`

### 5.5 반복·피로시험

- 검지·중지 CENTER: 4Hz, 15초, 각 3세트
- 약지 CENTER: 3Hz, 15초, 3세트
- 소지 CENTER: 2.5Hz, 15초, 3세트
- 모든 측면 입력: 2.5Hz, 10초, 각 2세트
- 이후 일반 게임 입력을 모사한 무작위 12키 과제를 15분 수행한다.

**피로 Gate**

- 마지막 세트 성공률 `≥90%`
- 첫 세트 대비 성공률 감소 `≤7%p`
- discomfort 최고값 `≤3/5`, 시작 대비 증가 `≤1점`
- 저림·피부 통증·손가락 걸림 없음
- 소지만 먼저 지지면에서 이탈하거나 과도하게 굽혀지지 않음

### 5.6 P1 내구시험

- 대표 검지 카트리지: 각 방향 3,000회
- 약지·소지 카트리지: 각 방향 1,000회
- 합계 최소 15,000 actuation

전후 조건:

- 작동력 변화 `≤15%`
- 유격 증가 `≤0.20mm`
- 균열·백화·축 이탈·나사 풀림 없음
- 30회/방향 재시험 정확도 `≥95%`

## 6. P2 — OneGrip 본체 통합

### 6.1 통합 상태

다음을 모두 장착한 최종에 가까운 질량·형상으로 시험한다.

- 퍼티형 버티컬 그립
- 네 손가락 카트리지
- 손바닥 지지 및 퀵릴리스 스트랩
- 엄지 입력부 더미 또는 실제 부품
- 좌우·전후 기울임 관절과 고정 베이스
- 실제 배선과 커버

### 6.2 정적 도달·자세 검사

1. 손목을 중립에 가깝게 놓고 스트랩을 고정한다.
2. 네 CENTER, 여덟 측면 입력을 눈을 감고 각 5회 누른다.
3. 손가락·손바닥·손목의 기준점을 촬영한다.

설계 목표:

- 손목 신전 `≤15°`
- 요측/척측 편위 `≤10°`
- 12입력 도달률 `100%`
- 손가락 지문 중심의 캡 이탈 `≤3mm`
- 스트랩이 엄지 운동범위 또는 소지 혈류를 방해하지 않음
- 5분 중립 유지 시 자동 입력 0회

각도는 의료 판정이 아니라 상대 비교용 설계 목표다. 사용자의 구축 또는 관절 제한 때문에 중립이 불가능하면 본인의 편안한 기준 자세 대비 변화량을 기록한다.

### 6.3 기울임 중 입력 교란시험

그립을 좌·우·앞·뒤 최대 사용각의 80%로 유지하면서 손가락 입력을 시험한다.

- 각 기울임 방향에서 12입력을 각 10회: 방향당 120회
- 기울이는 동안 아무 손가락도 누르지 않는 30초 중립 시험
- 2초마다 기울임 방향을 바꾸는 동안 CENTER 입력 40회

**P2 교란 Gate**

- 기울임 유지 중 손가락 정확도 `≥95%`
- 그립 기울임만으로 발생한 손가락 이벤트 `0회`
- 다른 손가락 우발 입력률 `≤2%`
- 손이 그립에서 축방향으로 미끄러진 거리 `≤5mm`
- 스트랩·손바닥 지지가 힘을 받아 소지에만 하중이 몰리지 않음

### 6.4 실제 과제

| 과제 | 시간 | 기록 |
|---|---:|---|
| PC 게임 훈련 과제 | 15분 | 키 정확도, 반복 실패, 손 재배치 |
| 웹/YouTube 조작 | 10분 | 탭 이동, 재생, 전체화면 성공률 |
| 콘솔 메뉴 또는 게임 | 15분 | 기울임과 손가락 동시입력 오류 |
| 휴식 없이 혼합 사용 | 20분 | discomfort, 피로, 자동 입력 |

과제 성공률 `≥90%`, 손가락 모듈 때문에 발생한 명확한 오입력 `≤2%`, 20분 후 discomfort `≤3/5`를 목표로 한다.

### 6.5 최종 내구·정비시험

- 검지 대표 카트리지 각 방향 10,000회
- 나머지 카트리지 각 방향 2,000회
- 본체에서 카트리지 10회 탈착
- 배선 커넥터 10회 탈착
- 체결 나사 토크를 동일하게 한 뒤 입력력 재측정

**P2 최종 Gate**

- 파손 및 기능 상실 0회
- 작동력 변화 `≤20%`
- 이웃 입력률 최종 `≤2%`
- 카트리지 1개 교체시간 `≤10분`
- 교체 후 별도 셸 가공 없이 입력력 심 조정만으로 정상화

## 7. 실패 원인별 수정 규칙

| 관찰 | 우선 수정 | 금지할 임시방편 |
|---|---|---|
| CENTER 때 LEFT/RIGHT 동시입력 | 중앙 가이드 유격 축소, 측면 패들 간극 증가, 하드스톱 앞당김 | 긴 펌웨어 잠금으로 숨기기 |
| LEFT/RIGHT 누락 | 측면 레버비 증가, 접촉각 3° 단위 수정, 프리로드 감소 | 손가락을 크게 옮기도록 안내 |
| 정지 상태 자동입력 | 프리로드 증가, 지지면 높이 증가, 소프트 패드 얇게 | 전체 스위치 감도만 낮추기 |
| 반복 중 복귀 지연 | 축 간극·마찰 확인, 금속축 사용, 패들 질량 감소 | 강한 스프링으로 작동력 증가 |
| 소지 작동력 과다 | 내부 지렛팔 연장, 스위치 후퇴, 전용 소지 패들 | 검지 STL 균일 축소 |
| 약지/소지 교차입력 | 모듈 전후·각도 분리, 지지 능선 조정, 캡 폭 축소 | 해당 입력 삭제 |
| 출력 개체마다 감각 다름 | 공차 쿠폰 재선정, 스위치 슬롯·심 추가 | 매번 수작업 사포질로만 보정 |
| 축·키 백화/균열 | 두께 증가, 적층 방향 변경, 금속축·필렛 적용 | 접착제로 균열만 덮기 |

한 번에 한 parameter만 바꾸고 revision을 올린다. 형상 변경 전후 데이터를 같은 참여자·같은 순서로 비교한다.

## 8. 결과 보고 양식

### 8.1 요약표

| Stage | Revision | Participant | Finger/Variant | Accuracy | Adjacent | Double | Repeat | Force | Effort | Discomfort | Pass |
|---|---|---|---|---:|---:|---:|---:|---:|---:|---:|---|
| P0 |  |  |  |  |  |  |  |  |  |  |  |

### 8.2 변경 기록

```text
revision:
changed_parameter:
old_value:
new_value:
reason:
expected_effect:
measured_effect:
files_printed:
decision: keep / revert / retest
```

### 8.3 최종 승인 체크리스트

- [ ] A/B/C를 동일 조건에서 P0 측정했다.
- [ ] 선택안이 단일 입력과 반복 입력 Gate를 통과했다.
- [ ] 소지를 별도 형상·힘으로 검증했다.
- [ ] P1에서 약지·소지 교차입력을 측정했다.
- [ ] P2에서 그립 기울임 중 자동입력이 없었다.
- [ ] 스위치 대신 셸 하드스톱이 과행정 하중을 받는다.
- [ ] 최종 FDM 간극과 프린터 프로파일을 기록했다.
- [ ] 카트리지 교체 후 재보정 절차가 10분 이내다.
- [ ] 대상 사용자 멘토의 별도 결과와 수정사항을 남겼다.
- [ ] 불합격 항목을 펌웨어로 숨기지 않았다.

## 9. 8월 28일 일정 보호용 판단 시점

- `8/14`: 공차 쿠폰과 A/B/C P0 출력 시작
- `8/15`: 기계 검사와 단일 입력 시험
- `8/16`: 반복·소지 시험 후 B 또는 A 확정
- `8/17~18`: 네 손가락 P1 출력·조립
- `8/19`: P1 정확도·교차입력 시험, 손가락별 geometry 동결
- `8/20~22`: OneGrip P2 통합 출력·배선
- `8/23~24`: 기울임 교란·실제 과제
- `8/25~26`: 내구·재시험 및 예비 카트리지 제작
- `8/27`: 멘토 확인·시연 리허설
- `8/28`: 최종 완료

`8/16`까지 B가 P0 Gate를 통과하지 못하면 C를 추가 튜닝하지 않고 A로 전환한다. `8/19` 이후에는 손가락 접촉 형상을 크게 바꾸지 않고 심, 하드스톱, 모듈 위치만 조정한다.

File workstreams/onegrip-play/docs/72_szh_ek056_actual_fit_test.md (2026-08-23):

# 72 — SZH-EK056 actual-part physical fit test fixture

## 1. Status

이 결과는 **TEST FIXTURE / SACRIFICIAL PROTOTYPE**이다. Production OneGrip geometry가 아니다.

| gate | result |
|---|---|
| local printable fit fixture | **GENERATED / PASS** |
| actual SZH-EK056 integration | **HOLD — PHYSICAL TEST REQUIRED** |
| stock knob as final packaging constraint | **EXCLUDED** |
| custom OneGrip knob adapter | **NOT CREATED** |
| N1/N2 production geometry modification | **0** |
| Finger / Thumb / shell production geometry modification | **0** |

실물 결과가 나오기 전에는 provisional `PCB ↔ N1/N2`, `N1 T4 ≈ 1.108 mm`, shaft/gimbal sweep, wiring HOLD를 해결하기 위한 production 수정으로 넘어가지 않는다.

## 2. Deliverables

Mandatory assembly는 실제 OneGrip world coordinate에 놓인 fixture body와 N1/N2 carrier를 함께 보존한다.

| file | purpose | bytes | SHA-256 |
|---|---|---:|---|
| `build123d_workbench/out/szh_actual_fit_fixture/SZH_EK056_ACTUAL_FIT_FIXTURE.step` | labeled world-coordinate assembly | 7,255,751 | `80193369d6bde8d8e32564a8ef92a31eb5f31539bcf38423559e7d2b75e821e4` |
| `build123d_workbench/out/szh_actual_fit_fixture/SZH_EK056_ACTUAL_FIT_FIXTURE.stl` | mandatory multi-body mesh | 2,656,984 | `b6bf538f6116f238fb3596f3d8116e06c4bc1bcb852b525d6d1c8b03dfa8f822` |
| `build123d_workbench/out/szh_actual_fit_fixture/SZH_EK056_ACTUAL_FIT_FIXTURE_BODY.step` | shell/Backplate/sacrificial frame print split | 6,484,410 | `6ee89d0918bb8e79876cac8f7d4c74d0233c318b1f22a2d20c667ea9294b0bb9` |
| `build123d_workbench/out/szh_actual_fit_fixture/SZH_EK056_ACTUAL_FIT_FIXTURE_BODY.stl` | recommended body print | 2,558,184 | `fb3d6c40a94dc6b29a00d9d16ff2f40da00e04023ff7d4fc6d96f5a0c470db48` |
| `build123d_workbench/out/szh_actual_fit_fixture/SZH_EK056_ACTUAL_FIT_FIXTURE_N1_N2_CARRIER.stl` | approved carrier exact-copy print split | 107,684 | `14b0ba5426e7299944c411f88ca02d95dd6ad27f65e64fa3212e23cc336096fb` |
| `build123d_workbench/out/szh_actual_fit_fixture/szh_ek056_actual_fit_fixture.json` | coordinates, hashes, crop, support and memory record | — | generated record |

Generator: `build123d_workbench/szh_actual_fit_fixture.py`.

### Recommended print set

Mandatory STL은 조립 좌표 검증용 multi-body다. 실제 출력은 다음 두 파일을 쓰는 편이 안전하다.

1. `SZH_EK056_ACTUAL_FIT_FIXTURE_BODY.stl`
2. `SZH_EK056_ACTUAL_FIT_FIXTURE_N1_N2_CARRIER.stl`

단위는 **mm**다. Body는 slicer에서 한 개의 rigid body로 회전할 수 있지만, 내부 shell/Backplate component를 따로 자동 정렬하면 안 된다. N1/N2 carrier는 별도 출력한 뒤 승인된 seating position에 넣는다. Carrier fastening boss는 이번 범위에서 만들지 않았으므로 필요하면 외부 비기능 면에 low-tack putty 또는 테이프를 임시로 사용한다.

## 3. Preserved coordinate frame

| datum | value |
|---|---|
| approved joystick pivot datum, world mm | `(-0.216040, -23.149077, 40.496179)` |
| joystick axis / local +Z | `(0.000181854, 0.598493369, 0.801127739)` |
| local +X | `(0.001022863, -0.801127445, 0.598492917)` |
| local +Y | `(0.999999460, 0.000710605, -0.000757865)` |
| source geometry translation | `0.000 mm` |
| source geometry rotation | `0.000°` |
| original Backplate mount-hole centre plane | local `Z = 1.000000 mm` |
| local crop | `51 × 36 × 43 mm` |

JaD/JfD current shell과 lowered original Thumb Backplate는 위 좌표에서 잘라낸 local exact section이다. Crop boundary와 별도 희생형 frame/support만 새 geometry다. Shell inner surface, opening, N1/N2 상대 위치, Backplate mount reference는 이동하지 않았다.

Web reference의 `1.8 mm` axial sensitivity는 렌더에서 approximate module을 놓는 참고값일 뿐이다. 실제 모듈을 강제로 그 위치에 고정하는 hard locator는 만들지 않았다.

## 4. Fixture architecture

- Body: current JaD/JfD local shell section + lowered Backplate local section.
- Sacrificial foundation: open-centre `59 × 43 × 3 mm` frame.
- Structural links: crop 외곽에만 붙는 `3.2 mm` section support 6개.
- Carrier: docs/63 이후 승인된 N1/N2 carrier의 무수정 복사본.
- Printed switch: 없음. 실제 ITS-1105 또는 실측 dummy를 carrier에 넣는다.
- Printed joystick: 없음. 실제 SZH-EK056를 넣는다.
- Stock knob: 제거 상태로 시험한다.
- Stock header: 유지 상태로 시험한다.

Foundation의 중앙 후면, PCB/header 측면, N1/N1-T4 측면, N2 측면, shaft/gimbal 외측 opening이 열려 있다. `1.0–1.3 mm` wire 한 가닥을 rear / side / shell-wall 방향으로 직접 대볼 수 있다.

Embossed labels:

`N1`, `N2`, `PCB DATUM`, `JOYSTICK AXIS`, `+X`, `-X`, `+Y`, `-Y`, `N1 T4 CHECK`, `TEST ONLY`.

## 5. Print and preparation

1. Body와 carrier를 출력한다. Body의 여섯 support link와 foundation은 제거하지 않는다.
2. Stringing 또는 support residue는 access window에서만 제거한다. Shell inner surface, Backplate mount reference, carrier seating surface는 사포로 보정하지 않는다.
3. Carrier를 정확한 seating position에 dry-fit한다. 임시 고정재는 terminal/joystick 쪽이 아닌 외부 비기능 면에만 쓴다.
4. 실제 또는 dummy ITS-1105를 N1/N2에 넣는다. N1 T4를 절단·굽힘·연마하지 않는다.
5. 실제 SZH-EK056 stock knob를 제거한다. Stock header와 pin은 그대로 둔다.
6. 열린 후면에서 모듈을 손으로 넣어 neutral shaft를 OneGrip opening/axis에 맞춘다. Web-reference mounting holes에 억지로 맞추지 않는다.
7. 접촉 확인에는 얇은 마커, transfer ink, 종이/필름 feeler를 사용한다. 실제 부품 또는 production source를 갈아내지 않는다.

지그가 먼저 닿는 경우에만 fixture 내부를 파일/사포/rotary tool로 relief한다. Relief 위치와 대략 깊이를 아래 표에 기록한다.

## 6. Measurement sheet

### 6.1 Actual module metrology

| measurement | actual result | method / note |
|---|---|---|
| MODULE PCB X | `_____ mm` | caliper |
| MODULE PCB Y | `_____ mm` | caliper |
| MODULE PCB Z / thickness | `_____ mm` | bare PCB thickness |
| mounting-hole X pitch | `_____ mm` | hole centre-to-centre |
| mounting-hole Y pitch | `_____ mm` | hole centre-to-centre |
| mounting-hole diameter | `_____ mm` | 4 holes individually if different |
| joystick centre from PCB X datum | `_____ mm` | sign follows fixture labels |
| joystick centre from PCB Y datum | `_____ mm` | sign follows fixture labels |
| ACTUAL MOUNTING POSITION local X | `_____ mm` | relative to labeled axis/datum |
| ACTUAL MOUNTING POSITION local Y | `_____ mm` | relative to labeled axis/datum |
| ACTUAL MOUNTING POSITION local Z | `_____ mm` | relative to Backplate mount plane |
| X potentiometer max envelope | `_____ × _____ × _____ mm` | include terminals |
| Y potentiometer max envelope | `_____ × _____ × _____ mm` | include terminals |
| bottom switch max envelope | `_____ × _____ × _____ mm` | include solder legs |
| stock header max envelope | `_____ × _____ × _____ mm` | plastic + pins |

### 6.2 Shaft / future knob interface

Original printable knob reference bore is approximately `4.150813 × 3.150000 mm`, depth `9.000 mm`. 이것을 근거로 실물 shaft를 PASS 처리하지 않는다.

| measurement | actual result | note |
|---|---|---|
| SHAFT PROFILE | `ROUND / D / KEYED / OTHER: _____` | photo/sketch 권장 |
| SHAFT X | `_____ mm` | maximum section |
| SHAFT Y | `_____ mm` | orthogonal maximum section |
| exposed shaft length | `_____ mm` | housing/shoulder to end |
| available insertion length | `_____ mm` | usable knob engagement only |
| shoulder / step position | `_____ mm` | if present |
| original knob direct fit | `YES / NO / UNKNOWN` | force-fit 금지 |

### 6.3 N1/N2 physical contact

| check | result |
|---|---|
| N1 CONTACT | `NONE / TOUCH / INTERFERENCE` |
| N1 INTERFERENCE LOCATION | `________________________________` |
| N1 T4 direct contact | `NONE / TOUCH / INTERFERENCE` |
| N1 MANUAL RELIEF REQUIRED | `_____ mm approximate / NONE` |
| N2 CONTACT | `NONE / TOUCH / INTERFERENCE` |
| N2 INTERFERENCE LOCATION | `________________________________` |
| N2 MANUAL RELIEF REQUIRED | `_____ mm approximate / NONE` |
| stock header blocks insertion | `YES / NO` |
| stock header contact location | `________________________________` |

### 6.4 Shaft/gimbal tilt

Neutral shaft를 `JOYSTICK AXIS`에 맞춘 뒤 stock knob 없이 천천히 움직인다. 억지로 hard stop을 넘기지 않는다.

| direction | result | first contact location / note |
|---|---|---|
| CENTER | `FREE / TOUCH / BLOCKED` | `____________________________` |
| +X TILT | `FREE / TOUCH / BLOCKED` | `____________________________` |
| -X TILT | `FREE / TOUCH / BLOCKED` | `____________________________` |
| +Y TILT | `FREE / TOUCH / BLOCKED` | `____________________________` |
| -Y TILT | `FREE / TOUCH / BLOCKED` | `____________________________` |
| observed maximum +X | `_____° / _____ mm at shaft end` | method: `_____` |
| observed maximum -X | `_____° / _____ mm at shaft end` | method: `_____` |
| observed maximum +Y | `_____° / _____ mm at shaft end` | method: `_____` |
| observed maximum -Y | `_____° / _____ mm at shaft end` | method: `_____` |

### 6.5 One-wire departure probe

`1.0–1.3 mm` class insulated wire 한 가닥만 손으로 대본다. Production channel을 만들거나 carrier를 깎지 않는다.

| route | result | tight/contact location |
|---|---|---|
| REAR WIRE DEPARTURE | `CLEAR / TIGHT / BLOCKED` | `____________________________` |
| SIDE WIRE DEPARTURE | `CLEAR / TIGHT / BLOCKED` | `____________________________` |
| SHELL-WALL DEPARTURE | `CLEAR / TIGHT / BLOCKED` | `____________________________` |
| preferred physical route | `REAR / SIDE / SHELL-WALL / NONE` | `____________________________` |

## 7. Review renders

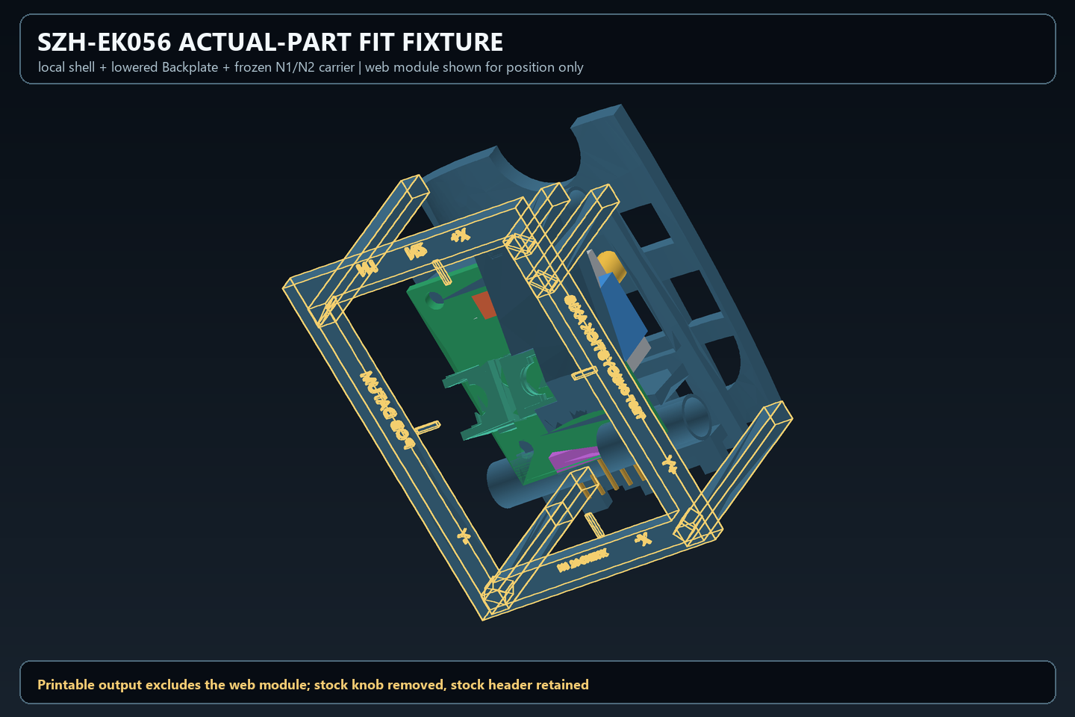
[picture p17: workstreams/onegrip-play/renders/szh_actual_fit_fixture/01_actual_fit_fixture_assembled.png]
Actual fit fixture assembled


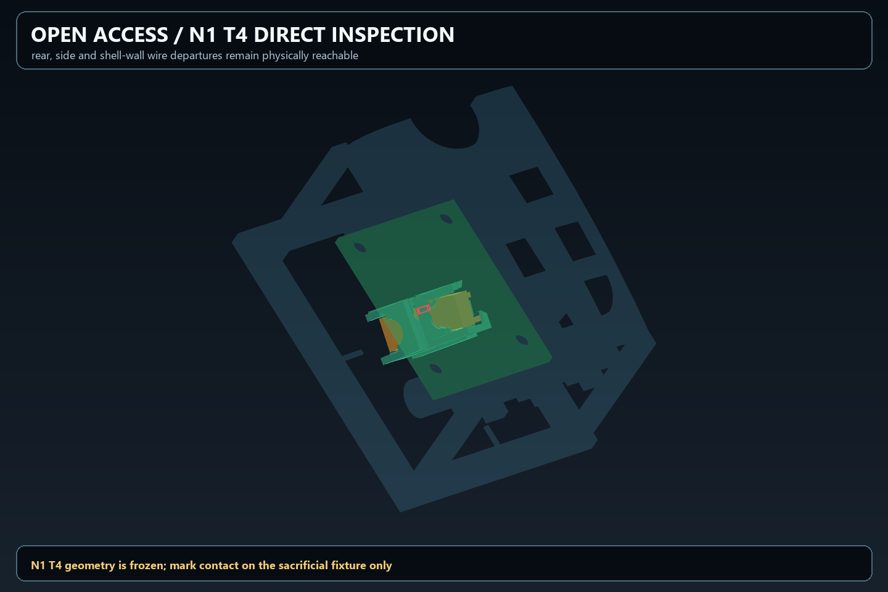
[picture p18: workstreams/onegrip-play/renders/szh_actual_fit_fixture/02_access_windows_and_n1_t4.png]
N1 T4 access


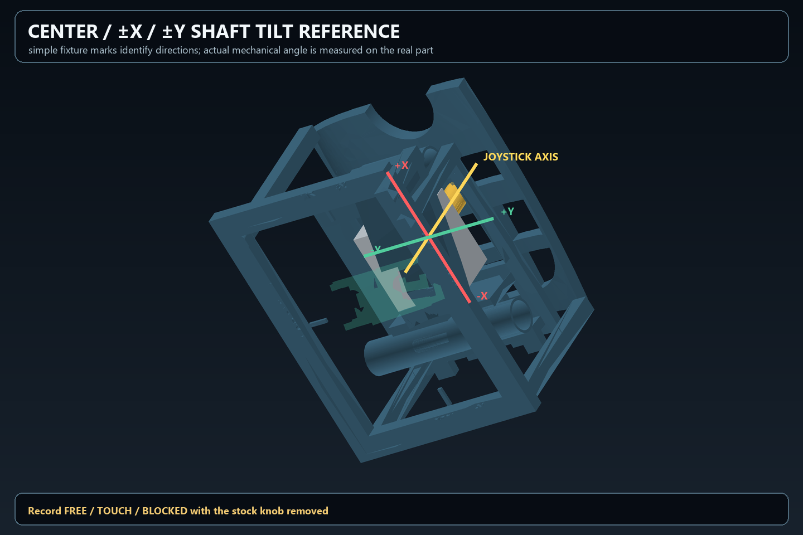
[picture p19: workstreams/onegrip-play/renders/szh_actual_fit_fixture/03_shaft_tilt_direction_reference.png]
Shaft tilt reference


Web module의 green PCB/colored body는 위치 설명용 translucent reference다. STEP/STL print geometry에는 포함되지 않는다.

## 8. Verification record

| verification | result |
|---|---|
| mandatory STEP re-import | **PASS** |
| STEP solid count | `74` |
| STEP leaf-solid volume sum, serialization diagnostic only | `15157.361121 mm³` |
| nested root mass property, serialization diagnostic only | `4127.525150 mm³` |
| canonical carrier ↔ exported carrier | **EXACT COPY / distance 0.000000 mm** |
| web PCB/gimbal/header/shaft solids in fixture STEP | **ABSENT** |
| local full-shell crop operations | `2`, serial |
| full shell STEP/STL export | `0` |
| web joystick exported into fixture | `NO` |
| custom knob/adapter generated | `NO` |
| source hash before/after | **IDENTICAL** |
| peak process RSS | `525.3 MB` |
| production geometry modification | **0** |

Key frozen source guards:

| source | SHA-256 |
|---|---|
| `N1_N2_SHARED_CARRIER_N1_LOCAL.step` | `2485e34f8716395459f1f7b10384fd73a33695472f9aae689cf321d583830756` |
| `JAD_FINGER_V2.step` | `a477aa79e55ddb21fb2a45c7f616544f6eb4844b593f61cf7d45303476c5a762` |
| `JFD_FINGER_V2.step` | `d457d5d9b305a4c7d77e21aab3cb7d33336d672d4d8bf031e6158de44c26ad50` |
| `THUMB_TARGET_EXACT_MODULE.step` | `adc870ffaf55a9342d62df89f162827a744bdf1d43060c0fbb69f7c8e8089fe9` |

## 9. Stop gate

실물 측정표와 contact/tilt/wire 결과가 채워질 때까지:

- N1/N2 terminal 수정 금지
- N1/N2 carrier 수정 금지
- Thumb/shell 수정 금지
- SZH mounting adapter production 설계 금지
- final wire channel 생성 금지
- custom knob bore/adapter 변경 금지

**STOP — actual SZH-EK056 physical result required.**

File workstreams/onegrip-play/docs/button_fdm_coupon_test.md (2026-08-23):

# BUTTON FDM TEST COUPON V2 — P1S / 0.4 mm nozzle

## 결론과 범위

V1 G열의 옆삽입 포켓/좁은 핀 슬롯/공중에 생기는 포켓 지붕은 실물 FDM 시험에서 부적합으로 판정했다. V2는 **위에서 내려놓는 개방형 4코너 크래들 + 중앙 rear support + 별도 가이드 덱**으로 다시 만들었다.

OneGrip production STEP/carrier/source는 import, 수정, overwrite하지 않았다. 오픈소스 Thumb의 `PushBtn` exact STEP은 읽기 전용으로만 감사했고, 생성 스크립트에는 측정된 envelope 숫자만 독립 parameter로 기록했다.

## 생성물과 부품

- `build123d_workbench/out/button_fdm_coupon/BUTTON_FDM_TEST_COUPON.step`
- `build123d_workbench/out/button_fdm_coupon/BUTTON_FDM_TEST_COUPON.stl`
- print layout: 82.000 × 83.250 × 13.500 mm
- 총 12 solids: base/cradles 1 + 뒤집어 쓰는 guide deck 1 + caps 5 + C-clips 5
- 별도 준비: **M3×10 mm screw 2개**. 덱은 Ø3.40 clearance, base boss는 Ø2.80 self-tapping pilot이다.

`P`는 switch-body 관통 공차 게이지, `G`는 완성 기구의 guide bore 번호다. `G4.80`과 `P6.40` 테두리는 최초 seed 표시일 뿐이며, 실물 P6.30 합격 결과가 V2 G열의 body 기준이다.

## V2가 새로 반영한 실물 형상

| 항목 | V2 값/처리 |
|---|---:|
| 사용자의 measured body | 6.12 × 6.05 mm |
| G열 body locator | 6.30 mm |
| body 이론 side clearance X/Y | 0.090 / 0.125 mm |
| 네 모서리 전면 돌기 | 4 × Ø1.00, 중심 ±2.25, 높이 0.50 mm |
| 원본 formed-pin 최대 외폭 | 7.566 mm |
| 원본 pin rear reach | 3.52 mm |
| V2 아래쪽 pin 여유 깊이 | 4.20 mm |
| cap tail / contact | Ø4.50 / Ø3.00 mm |
| hard stop | 0.350 mm |

네 corner locator 사이의 네 방향은 완전히 열려 있다. 따라서 terminal root와 성형된 긴 핀이 좁은 slot을 통과할 필요가 없고, 핀을 자르거나 뿌리에서 꺾지 않는다. 중앙 4.00 mm pedestal만 housing 뒤 중앙을 받는다. 네 모서리 Ø1.00 돌기는 deck과 locator 어느 쪽에도 닿지 않는다.

## FDM 방향

1. STL을 multi-part 한 개 object로 가져오고 제공 방향/100% scale을 유지한다.
2. P1S / 0.4 mm nozzle, 0.20 mm layer, wall 3회 이상, support OFF로 시작한다.
3. 긴 guide deck은 **완성품 윗면이 build plate를 향하도록 이미 뒤집혀 있다.** 출력 후 뒤집어서 조립한다. 이 때문에 6.80 mm retention cavity가 출력 중 위로 열리고 공중 bridge/roof가 생기지 않는다.
4. 5개 guide bore는 모두 Z축 수직 hole이다. caps는 pad-face-down, C-clips는 flat으로 놓여 있다.
5. 첫 출력은 XY/hole compensation 0.00. 드릴, 리머, 사포, 윤활 없이 비교한다.

## 조립 순서

### P열 — body 공차 확인

1. 형님이 시험하신 것과 동일하게 **actuator/누르는 면이 아래쪽**을 향하게 한다.
2. 같은 switch를 P6.50부터 P6.30까지 넣고 아래에서 다시 밀어 뺀다.
3. 현재 실물 결과 `P6.30 = 아주 핏하게 삽입 가능`을 baseline으로 기록한다.

### G열 — 실제 누름 구조

1. switch를 **actuator 위 / 핀 아래** 방향으로 잡고 원하는 G 번호의 네 corner locator 사이에 수직으로 내려놓는다.
2. 핀은 locator 사이의 열린 방향과 아래 빈 공간으로 그대로 내려간다. **핀을 더 자르거나 억지로 좁은 홈에 넣지 않는다.** 중앙 pedestal에 housing 뒤 중앙만 닿으면 정상이다.
3. guide deck을 손에 들고, cap tail을 덱의 평평한 윗면에서 해당 원형 bore로 통과시킨다.
4. 덱의 6.80 mm 사각 cavity 쪽으로 나온 Ø3.50 groove에 flat C-clip을 옆으로 밀어 넣는다. clip의 열린 입구 방향은 아무 쪽이나 가능하며, 조립 후 cavity 벽이 clip 이탈을 막는다.
5. 필요한 cap을 장착한 deck을 뒤집어 cavity가 아래를 향하게 하고, switch actuator와 cap contact를 맞추며 수직으로 내린다.
6. 양 끝 Ø3.40 hole에 M3×10 screw 2개를 넣어 Ø2.80 pilot boss에 가볍게 self-tap한다. deck이 네 기둥 위에 닿은 뒤 더 조이지 않는다.
7. cap pad를 누른다. rest에서 clip은 cavity roof에 걸려 cap을 유지하고, 0.350 mm 후 clip 하단과 cap pad 하단이 동시에 printed deck에 닿아 hard stop을 만든다.
8. 분해는 screw 2개 → deck 수직 인양 → clip 옆으로 제거 → cap 인출 → switch 위로 인출 순서다.

## Guide 공차 기록

| G bore Ø mm | diametral clearance mm | radial clearance mm | wobble | binding | return | click feel | 100 cycles |
|---:|---:|---:|---|---|---|---|---|
| 4.70 | 0.200 | 0.100 |  |  |  |  |  |
| 4.75 | 0.250 | 0.125 |  |  |  |  |  |
| 4.80 | 0.300 | 0.150 |  |  |  |  |  |
| 4.85 | 0.350 | 0.175 |  |  |  |  |  |
| 4.90 | 0.400 | 0.200 |  |  |  |  |  |

100회 중 한 번도 걸리지 않고 모든 slow/off-axis release에서 복귀하는 가장 작은 G를 선택한 다음, 통과한 후보끼리 wobble을 비교한다.

## Pocket 공차 기록

| P square mm | X side clearance mm | Y side clearance mm | insertion | retention | removal / damage |
|---:|---:|---:|---|---|---|
| 6.30 | 0.090 | 0.125 |  |  |  |
| 6.35 | 0.115 | 0.150 |  |  |  |
| 6.40 | 0.140 | 0.175 |  |  |  |
| 6.45 | 0.165 | 0.200 |  |  |  |
| 6.50 | 0.190 | 0.225 |  |  |  |

## 실물 평가표

| 항목 | 결과 |
|---|---|
| printer / nozzle | Bambu Lab P1S / 0.4 mm |
| filament / 건조 상태 |  |
| layer / wall / line width |  |
| XY / hole compensation | 0.00 baseline |
| P6.30 재확인 |  |
| 선택 G |  |
| cap wobble |  |
| cap binding |  |
| slow/off-axis return 10+10회 |  |
| click feel |  |
| 실측 rest-to-stop travel |  |
| switch retention / removal |  |
| corner locator / wall damage |  |
| 25 / 50 / 100 cycle |  |
| 최종 선택 / 다음 보정 |  |

## 디지털 검사

- B-rep valid, connected base 1 solid, guide deck 1 solid: `PASS`
- cap 5 / retention clip 5 fragmentation: `PASS`
- minimum structural wall: 1.20 mm (`PASS >= 1.20`)
- body ↔ four-corner cradle unintended penetration: 0 mm³
- full uncut formed-pin envelope ↔ cradle penetration: 0 mm³
- four corner posts / actuator / body ↔ guide deck penetration: 0 mm³
- cap + C-clip ↔ deck penetration at rest: 0 mm³
- cap + C-clip ↔ deck penetration at 0.350 mm: 0 mm³, hard-stop faces only coincident
- production source import/write: 0

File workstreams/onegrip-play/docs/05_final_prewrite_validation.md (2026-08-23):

# CAD 수정 직전 최종 검증 (READ ONLY)

- 조회일 2026-08-19 / **CAD 수정 0건.** GET 요청과 로컬 계산만 수행
- 재현:
  ```bash
  python scripts/shell_diff.py 2.0
  ```
- 대상: docs/04 에서 남긴 UNKNOWN 2건

---

## 0. 최종 판정

> ## GO
>
> 두 UNKNOWN 모두 규명되었고, **둘 다 신규 설계에 영향을 주지 않는다.**
>
> - Joystick_1/2 부피차의 **96.6%는 나사 체결 구조**(의도된 설계)
> - 나머지 3.4%는 Pitch 결합부의 소형 비대칭 — 신규 버튼에서 52 mm 이상 떨어짐
> - **신규 finger button 영역은 측정 한계 내에서 완전 대칭** (최대 차 0.10 mm)
> - HW504_B ×2 는 중복이 아니라 **서로 다른 두 body**(모듈 본체 + 가동 스틱)
> - `#hand_sign` 좌우 반전 방식에 **문제 없음**

---

## 1. 분석 방법

메시 비교로는 국소화가 되지 않아(구간별로 닫힌 메시가 아님) **레이 패리티**를 사용했다.

1. Joystick_2 를 X 반전해 Joystick_1 과 같은 쪽에 놓는다
2. (Y, Z) 격자 2 mm 마다 +X 방향 레이를 한 번 쏜다
3. 교차점 패리티로 '재료 구간'을 구하고 두 쉘의 총 재료 길이를 비교
4. 셀당 부피차 = (길이차) × 2 mm × 2 mm

검증: 판정불가 레이 0개, 총합 **+1.325 cm³** (massproperties 기준 **+1.270 cm³**, 격자 2 mm 오차 4%).

---

## 2. Joystick_1 / Joystick_2 부피차 원인

### 2.1 부피차의 Z 분포

| Z 구간 | 부피차 (J2 − J1) | 해당 위치 |
|---|---|---|
| −30 … −20 | **+0.317** | 나사 C (Z −21.35) |
| −20 … −10 | **+0.101** | 나사 C 연장 |
| +20 … +30 | **+0.503** | 나사 B (Z 23.07) |
| +40 … +50 | **+0.410** | 나사 A (Z 45.98) |
| −80 … −70 | −0.020 | Pitch 결합부 |
| 그 외 전 구간 | \|차\| ≤ 0.01 | — |

**차이가 나사 3개 위치에만 집중된다.** 그 외 구간은 전부 0에 수렴한다.

### 2.2 나사부 단면 실측 — 원인 확정

나사 B 축(Y −14.45, Z 23.07) 주변을 반경 방향으로 스캔한 결과:

| 축에서 거리 | Joystick_1 재료 | Joystick_2 재료 | 해석 |
|---|---|---|---|
| \|dy\| ≥ 4.0 mm | 3.00 mm | 2.98 mm | 쉘 벽만 — **동일** |
| \|dy\| ≈ 3.0–3.5 mm | 24.4 mm | 24.4 mm | **보스 외곽은 양쪽 동일 (⌀7)** |
| \|dy\| = 1.5–3.0 mm | **7.00 mm** | 24.49 mm | J1 에 **카운터보어** |
| \|dy\| < 1.5 mm | **0.00 mm** | 14.49 mm | J1 관통, J2 는 10 mm 탭홀 |

나사 축을 그대로 관통시킨 결과:

| 나사 | Joystick_1 재료 | Joystick_2 재료 |
|---|---|---|
| A (Z 45.98) | **0.00 mm** | 12.56 mm |
| B (Z 23.07) | **0.00 mm** | 14.49 mm |
| C (Z −21.35) | **0.00 mm** | 9.59 mm |

### 2.3 결론

```
Joystick_1 = 나사 머리 쪽  : ⌀3.5 관통 clearance hole + 카운터보어  → 재료 제거 많음
Joystick_2 = 나사 체결 쪽  : ⌀2.7 탭홀 깊이 10 mm                  → 재료 제거 적음
```

보스 길이 24.49 mm 중 J2 에 남은 재료 14.49 mm → **탭홀 깊이 정확히 10.0 mm**.
`#screw_depth = 10 mm` 와 일치하고, M3×16 나사가 J1 관통부(약 6 mm) + J2 탭홀(10 mm)로
정확히 소진된다. **설계 의도대로다.**

피처 트리와도 일치한다. `Screw_holes`(#34)는 `Mirror 1`(#33) **이후**에 있고,
Extrude 18·19(ADD)로 양쪽에 보스를 세운 뒤 Extrude 20·21·22(REMOVE)로
한쪽에는 클리어런스·카운터보어를, 다른 쪽에는 탭홀을 판다.
**미러 이후에 의도적으로 만든 비대칭이다.**

### 2.4 분류

| 분류 | 부피차 | 비중 | 판정 |
|---|---|---|---|
| **screw / fastener 관련** | **+1.331 cm³** | **96.6%** | **의도된 설계. 정상** |
| pitch attachment 관련 | −0.045 cm³ | 3.4% | §3 참조 |
| thumb controls 관련 | 0 | 0% | 없음 |
| shell opening 관련 | 0 | 0% | 없음 (개구부는 완전 대칭) |
| construction artifact | ±0.11 mm 수준 | 무시 | 테셀레이션 노이즈 |
| 실제 비대칭 외형 | **0** | **0%** | **없음 — 외피는 완전 대칭** |
| 기타 | 0 | 0% | — |

합계 +1.331 − 0.045 = **+1.286 cm³** ≈ massproperties 실측 +1.270 cm³.

---

## 3. 잔여 비대칭 (Pitch 결합부)

나사가 아닌 유일한 실제 차이:

| 항목 | 값 |
|---|---|
| 위치 | Y 35 … 37, Z −70 … −72 (그립 **후방 최하단**) |
| 형태 | Joystick_1 에만 존재하는 X방향 두께 **5.00 mm** 형상 |
| 부피 | 약 **0.045 cm³** (전체 차이의 3.4%) |
| Pitch 탱 점유 구간(Z −74…−58) 내부 | **예** |
| 신규 INDEX row(Z +9)까지 거리 | **약 80 mm** |
| 신규 MIDDLE row(Z −6)까지 거리 | **약 65 mm** |

추정 원인: 피처 트리에서 grip↔Pitch 결합부를 **두 쉘에 대해 별도 체인**으로 만든다
(`Extrude 14 → Boolean 2 → Delete 1 → Boolean 3` / `Extrude 15 → Boolean 4 → Delete 2 → Boolean 5`).
미러가 아니라 각각 작성된 연산이므로 소폭 차이가 남을 수 있다.
**정확한 정체는 미확정**이나, 크기·위치 모두 신규 설계와 무관하다.

그 외 (Y 26…36, Z −65…−66)과 (Y 44, Z −57)에서 관측된 ±0.05 ~ 0.11 mm 차이는
테셀레이션 chord tolerance(0.15 mm) 이내로 **노이즈**다.

---

## 4. 신규 finger button 영역 대칭성

| 영역 | 부피차 | **최대 재료 길이차** | 차이 셀 수 |
|---|---|---|---|
| INDEX (Z +3 … +15) | +0.0001 cm³ | **0.10 mm** | 5 |
| MIDDLE (Z −12 … 0) | +0.0004 cm³ | **0.10 mm** | 1 |

최대 차이 0.10 mm 는 테셀레이션 chord tolerance(0.15 mm) **이하**다.
즉 측정 한계 내에서 **두 쉘은 신규 버튼 영역에서 완전한 미러**다.

- 외피 형상 대칭 ✔
- 내부 캐비티 대칭 ✔
- 벽 두께 대칭 ✔ (양쪽 2.98–3.01 mm)
- 이 영역에 나사 보스·엄지 구조·Pitch 결합부 **모두 없음** ✔

가장 가까운 비대칭 요소는 나사 B 보스(Z 20–26)로, INDEX row 상단(Z 13)에서 **7 mm 이상** 위다.
docs/04 에서 확인한 holder 여유 4.20 mm 는 이미 이 보스를 고려한 값이다.

---

## 5. `#hand_sign` 좌우 반전 방식 검토

**판정: 문제 없음.**

| 검토 항목 | 결과 |
|---|---|
| 신규 버튼 영역 좌우 대칭 | **완전 대칭** (§4) → 반전해도 동일한 형상 위에 앉는다 |
| 반전 시 DOMINANT 쉘 변경 | Joystick_2(탭홀 측) → Joystick_1(카운터보어 측) |
| 그 변경이 holder 여유에 미치는 영향 | **없음.** 보스 **외곽 ⌀7 은 양쪽 동일**하고, 카운터보어는 그 안쪽 재료만 더 파낸다. docs/04 의 나사 여유는 ⌀7 외곽 기준으로 계산했으므로 반전해도 값이 나빠지지 않는다 |
| 엄지 버튼·조이스틱 | 분할면 기준 대칭 배치 → 반전 영향 없음 |
| Pitch 결합부 비대칭(§3) | 손 방향과 무관한 기구 결합부. 영향 없음 |

**단, 반전 시 함께 결정할 사항이 하나 있다:**
나사 머리가 항상 같은 쪽(예: 사용자 기준 바깥쪽)에서 들어가게 하려면
`Screw_holes` 계열(Extrude 20·21·22)의 좌우도 함께 뒤집어야 한다.
이는 **상류 피처**이므로, 반전 버전을 만들 때 별도 결정이 필요하다.
초판(한쪽 손)에서는 해당 사항 없음.

---

## 6. HW504_B ×2 의 정체

**판정: 중복 인스턴스가 아니다. 서로 다른 두 body 다.**

| | 인스턴스 \<1> | 인스턴스 \<2> |
|---|---|---|
| **partId** | **JFH** | **JFD** |
| elementId | `c349d3fc572261fbfb95897f` (동일) | 동일 |
| configuration | default | default |
| 부피 | **1.461 cm³** | **0.767 cm³** |
| bbox X | −15.50 … 11.50 (27.0) | −8.50 … 8.50 (17.0) |
| bbox Y | −1.25 … 13.00 (14.25) | 1.00 … 20.00 (19.0) |
| bbox Z | −19.46 … 19.46 (38.9) | −9.10 … 3.90 (13.0) |
| 어셈블리 원점 | (−6.472, −40.201, 53.746) | (−6.477, −40.272, 53.800) |

### mate 연결

| mate 이름 | 참조 |
|---|---|
| `Joystick_module` | **\<1> (JFH)** 만 |
| `Small_joystick_attachment` | **\<2> (JFD)** 만 |
| `Joystick_inside_part` | \<1> 과 \<2> 둘 다 |

### 해석

`HW504_B` Part Studio 에 **solid body 가 2개**(JFH, JFD) 있고, 둘 다 이름이 `HW504_B` 다.
어셈블리는 이 둘을 각각 한 번씩 인스턴스화한다.

- **JFH (\<1>, 27 × 14.25 × 38.9 mm)** = 모듈 본체 / 고정부.
  `Joystick_module` mate 로 쉘에 고정된다
- **JFD (\<2>, 17 × 19 × 13 mm)** = 가동 스틱부.
  `Small_joystick_attachment` mate 로 스틱 캡과 연결된다

원점이 0.07 mm 차이나는 것은 **두 body 의 로컬 원점이 다르기 때문**이며,
같은 부품을 두 번 넣은 것이 아니다.

> **docs/00 §6 및 docs/04 §11 정정:**
> "HW504_B 가 2개인 이유 UNKNOWN / 중복 인스턴스로 보임" 이라고 적은 것은 **틀렸다.**
> 실제로는 **엄지 조이스틱 1개가 고정부 + 가동부 2 body 로 모델링된 것**이며 정상이다.
> 신규 설계에서 "조이스틱 2개"로 취급하면 안 된다.

---

## 7. 결과 요약

| # | 질문 | 답 |
|---|---|---|
| A | Joystick_1/2 차이 원인 | 나사 체결 구조 96.6% (J1=클리어런스+카운터보어, J2=10 mm 탭홀). 나머지 3.4%는 Pitch 결합부 소형 비대칭 |
| B | 신규 finger button 영역 좌우 대칭? | **YES** — 최대 차 0.10 mm (테셀레이션 노이즈 이하) |
| C | `#hand_sign` 방식 문제? | **없음.** 반전 시 나사 머리 방향만 별도 결정 |
| D | HW504_B ×2 정체 | 중복 아님. 모듈 본체(JFH) + 가동 스틱(JFD) 2 body |
| E | CAD 수정 단계 진행? | **GO** |

---

## 8. GO 전 남은 비기술적 선행 조건

기술적 차단 요소는 **전부 해소되었다.** 남은 것은 다음뿐이다.

1. **사용자 소유 사본 문서** — 원본은 Adam Simon 소유라 수정 불가.
   Copy workspace / Fork 후 did · wid 필요
2. **원본 라이선스 조건** 확인 (public ≠ 파생·배포 허용)
3. **오른손 / 왼손 초판 방향** 결정 (구조상 반전 가능함은 §5에서 확인)

---

## 9. 확정된 신규 설계 파라미터 (변경 없음)

```text
분할면        X = 0 (유지). Mirror 1 유지. 상류 피처 무수정
INDEX  row    Z = +9.0    s = −27.5 / −16.5 / −5.5 / +5.5
MIDDLE row    Z = −6.0    s = −27.5 / −16.5 / −5.5 / +5.5
row offset    dominant 방향 −11.0 mm
cap 8.0 / gap 3.0 / pocket 6.4 / clearance 0.2 / cap height 4.0
holder 축     각 위치의 실제 local 3D surface normal 정렬 (OPTION B)
shell 소유    DOMINANT 3 + OPPOSITE 1  (분할면 걸치는 버튼 0개)
유지 대상     엄지 버튼 8개, 엄지 조이스틱(2 body), 분할면, 나사 3개, Pitch 결합부
```

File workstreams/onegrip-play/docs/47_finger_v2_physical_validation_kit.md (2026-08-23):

# OneGrip Play — Finger Controls V2 Physical Validation Kit

## 1. Scope and status

이 문서는 Finger Controls V2의 **FDM 현물 검증용 로컬 build123d 키트**를 기록한다.

- Onshape read/write: **0건**
- production Finger V2 geometry/parameter 변경: **0건**
- source: 검증 완료된 production STEP/STL을 read-only reference로 사용
- digital printability: **PASS**
- physical validation kit: **READY**
- physical Finger V2: **NOT YET VALIDATED**
- production Finger V2 freeze: **PENDING USER FDM RESULTS**

`DIGITAL PRINTABILITY PASS`는 형상 유효성, 간섭, 운동 범위, STL 유한성 및 배치 검사를 통과했다는 뜻이다. 실제 프린터의 수축, elephant foot, 압출 편차, 표면 거칠기와 조립 감각은 포함하지 않는다.

## 2. Production baseline protection

검증 키트는 `build123d_workbench/out/finger_controls_v2/`의 production 산출물을 불러와 별도 폴더에 파생 생성한다. production 파일과 설계 파라미터를 덮어쓰지 않는다.

검증 gate:

- production source PASS 유지
- production parameter unmodified
- 최종 키트 형상 valid solid
- unexpected fragment 0
- switch pocket 내부 support-free
- cap guide 내부 support-free

## 3. Kit inventory

### Kit A — ITS-1105 pocket fit coupon

파일:

- `ITS_POCKET_FIT_COUPON.stl`
- `ITS_POCKET_FIT_COUPON.step`

한 개의 평판 위에 6.30 / 6.35 / 6.40 / 6.45 / 6.50 mm 포켓을 배치했다. 각 포켓에 치수를 양각 표기했고, production nominal인 6.40 mm에는 프레임을 추가했다.

목적:

- 실제 ITS-1105 실물의 삽입력 확인
- 프린터별 XY 치수 편차 확인
- production 치수 변경 전 가장 적절한 포켓 선택

### Kit B — I4 one-button function coupon

파일:

- `ONE_BUTTON_I4_JAD_SHELL.stl`
- `ONE_BUTTON_I4_JFD_CLOSURE.stl`
- `KIT_I4_carrier.stl`
- `KIT_I4_cap.stl`
- `ONE_BUTTON_FUNCTION_COUPON.step`
- `ONE_BUTTON_FUNCTION_COUPON.stl` — 조립 상태 visual/reference mesh

production I4 주변 외피를 실제 곡률과 개구부가 남도록 잘라 만든 최소 기능 쿠폰이다. 스위치 삽입, 캐리어 장착, 캡 이동, click, return을 가장 적은 출력량으로 확인한다.

### Kit C — N2 seam function coupon

파일:

- `N2_SEAM_JAD_SHELL.stl`
- `N2_SEAM_JFD_SHELL.stl`
- `KIT_N1_N2_shared_carrier.stl`
- `KIT_N2_cap.stl`
- `N2_SEAM_FUNCTION_COUPON.step`
- `N2_SEAM_FUNCTION_COUPON.stl` — 조립 상태 visual/reference mesh

N2 중심을 기준으로 양쪽 production shell interface를 모두 포함한다. 실제 N1/N2 shared carrier와 N2 cap을 사용해 seam closure, cap rubbing, 조립 순서와 배선 접근성을 확인한다.

### Kit D — cropped 1:1 eight-button functional section

파일:

- `FINGER_V2_SECTION_JAD_SHELL.stl`
- `FINGER_V2_SECTION_JFD_SHELL.stl`
- `KIT_*.stl` carrier 5개
- `KIT_*_cap.stl` cap 8개
- `FINGER_V2_FUNCTIONAL_SECTION.step`
- `FINGER_V2_FUNCTIONAL_SECTION.stl` — 조립 상태 visual/reference mesh

전체 하우징 대신 Finger V2의 I2, I3, I4, M3, M4, N1, N2, N3 구간만 1:1로 잘랐다. 외피 곡률, 8개 개구부, 모든 캐리어/캡, 실제 ITS-1105 envelope를 유지한다. 실제 조립에는 ITS-1105 8개가 필요하다.

## 4. Digital motion audit

모든 버튼을 production local axis 방향으로 검사했다.

| Button | REST | PARTIAL | FULL | shell / carrier / housing / adjacent-cap intersection |
|---|---:|---:|---:|---:|
| I2 | 0.000 mm | 0.175 mm | 0.350 mm | 0 mm³ |
| I3 | 0.000 mm | 0.175 mm | 0.350 mm | 0 mm³ |
| I4 | 0.000 mm | 0.175 mm | 0.350 mm | 0 mm³ |
| M3 | 0.000 mm | 0.175 mm | 0.350 mm | 0 mm³ |
| M4 | 0.000 mm | 0.175 mm | 0.350 mm | 0 mm³ |
| N1 | 0.000 mm | 0.175 mm | 0.350 mm | 0 mm³ |
| N2 | 0.000 mm | 0.175 mm | 0.350 mm | 0 mm³ |
| N3 | 0.000 mm | 0.175 mm | 0.350 mm | 0 mm³ |

REST에서 스위치 액추에이터까지의 nominal pre-contact gap은 약 0.050 mm다. PARTIAL 및 FULL 상태에서는 접촉 거리 0이며 hard-body 관통은 없다. 이 결과는 형상 운동 가능성을 의미하며 출력 표면 마찰과 스위치 click 감각은 현물로 확인해야 한다.

## 5. FDM tolerance probe

분석은 가장 불리한 상관 오차인 `cavity shrink + mating part growth`를 가정한다.

### ITS pocket versus switch body

Nominal:

- pocket: 6.40 mm
- BODY_X: 6.18 mm → diametral 0.22 mm / per-side 0.11 mm
- BODY_Y: 6.12 mm → diametral 0.28 mm / per-side 0.14 mm

| Correlated error | Pocket | BODY_X / BODY_Y | X/Y diametral clearance | Result |
|---:|---:|---:|---:|---|
| ±0.00 mm | 6.40 | 6.18 / 6.12 | 0.22 / 0.28 | PASS |
| ±0.10 mm | 6.30 | 6.28 / 6.22 | 0.02 / 0.08 | MARGINAL |
| ±0.20 mm | 6.20 | 6.38 / 6.32 | -0.18 / -0.12 | INTERFERENCE |

따라서 6.40 mm는 nominal CAD에서 유효하지만 프린터 보정값 없이 production 치수로 고정할 수 없다. Kit A 결과를 먼저 사용한다.

### Cap versus opening

| Interface | Nominal diametral / per-side | ±0.10 worst | ±0.20 worst |
|---|---:|---:|---:|
| standard 8.0 / 7.6 mm | 0.40 / 0.20 | 0.20 / 0.10 PASS | 0.00 / 0.00 MARGINAL |
| N2 8.4 / 7.6 mm | 0.80 / 0.40 | 0.60 / 0.30 PASS | 0.40 / 0.20 PASS |

N2는 seam 대응 여유가 유지된다. 표준 opening은 누적 ±0.20 mm에서 nominal gap이 소진되므로 실제 rubbing 검사가 필요하다.

## 6. Printability audit

- nozzle assumption: 0.4 mm
- carrier wall: 1.6 mm
- minimum functional wall: 1.2 mm
- final plate components: 20
- plate envelope: 189.21 × 106.66 × 25.04 mm
- nominal inter-part gap: 6.0 mm
- STL triangles: 35,138
- non-finite coordinates: 0
- unexpected disconnected fragments: 0

| Validation part | Orientation | Support | Critical support / bridge / overhang | Minimum wall / feature | Primary sensitivity |
|---|---|---|---|---|---|
| Kit A fit coupon | flat base on bed, pockets vertical | NO | downward overhang 0%; open pocket tops bridge 없음 | base 2.4 mm; pocket tower wall은 후보 간 동일 | pocket lower edge elephant foot, XY hole shrink |
| Kit B I4 JaD crop | packed broad crop face on bed | YES, exterior local only | packed mesh downward overhang 약 27.65%; shell exterior crop perimeter만 지지 | production shell wall 유지; 기능부 최저 1.2 mm | opening/guide 안쪽 support 접촉 금지 |
| Kit B I4 JfD closure | broad cut face on bed | NO | downward overhang 0% | production shell wall 유지 | mating face first-layer burr |
| Kit C N2 JaD crop | broad cut face on bed | NO 또는 극소 local | downward overhang 약 0.25% | production shell wall 유지; 기능부 최저 1.2 mm | seam edge와 N2 opening |
| Kit C N2 JfD crop | broad cut face on bed | YES, exterior local only | downward overhang 약 2.85% | production shell wall 유지; 기능부 최저 1.2 mm | seam edge와 opposite-shell clearance |
| Kit D JaD shell section | packed crop face on bed | YES, exterior only | downward overhang 약 17.91% | production shell wall 유지; 기능부 최저 1.2 mm | 8개 guide/opening 내부 support 금지 |
| Kit D JfD shell section | packed crop face on bed | YES, exterior only | downward overhang 약 20.25% | production shell wall 유지; 기능부 최저 1.2 mm | carrier seat와 seam 내부 support 금지 |
| carriers 5개 | broad rear plate on bed, C-channel upward | NO 또는 local bridge only | 개별 packed overhang 약 0.13–16.35%; pocket 내부 지지 금지 | wall 1.6 mm; 기능부 최저 1.2 mm | pocket lower edge와 terminal-channel stringing |
| caps 8개 | external pad face on bed, socket upward | NO | measured downward overhang 0% | production cap/actuator feature 유지 | actuator socket elephant foot/stringing |

표의 overhang 비율은 자동 선택된 `VALIDATION_PRINT_PLATE.stl` orientation에서 STL 삼각형 면적으로 계산했다. 수치가 큰 shell crop도 support를 기능성 포켓/guide 안쪽에 넣는 허가를 의미하지 않는다. support는 잘라낸 외부 둘레에서만 허용한다.

권장 방향:

- fit coupon: 평평한 바닥을 bed에 배치, support 없음
- caps: 외부 누름면을 bed에 배치, socket가 위를 향하게, support 없음
- carriers: 넓은 rear plate를 bed에 배치, C-channel이 위, support 없음 또는 bridge 부위만 국부 적용
- shell crops: 가능한 한 opening axis를 위로 두고 절단 외곽에만 support 적용

금지:

- switch pocket 내부 support
- cap guide/opening 내부 support
- actuator socket 내부 support

Elephant-foot 민감 부위는 switch pocket 하단, cap guide/opening edge, cap actuator socket이다. 첫 층 horizontal expansion 보정을 하지 않은 상태에서는 fit coupon 결과를 우선한다.

## 7. Print and validation order

1. Kit A만 먼저 출력한다.
2. 식힌 뒤 서포트·brim 잔여물을 제거하되 포켓을 줄로 확장하지 않는다.
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

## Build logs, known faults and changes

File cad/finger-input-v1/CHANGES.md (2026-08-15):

# Revision log

## V1 — 2026-08-13

- Created three CAD-level mechanisms for direct switches, independent paddles,
  and a shared rocker.
- Selected independent paddles for P0; kept direct switches as the schedule
  fallback and excluded the shared rocker from V1.
- Replaced the preliminary pivoting center key with a two-post straight guide
  after checking the official Lalboard mechanism.
- Moved the two guide posts outside the 6.2mm center-switch envelope.
- Added a 0.62mm shell stop gap: 0.50mm maximum pretravel + 0.12mm controlled
  travel after click.
- Increased PETG side pivot holes to Ø2.4mm for Ø2.0mm shafts.
- Reduced center anti-loss cross holes to Ø1.1mm for Ø1.0mm pins, leaving at
  least 0.85mm nominal wall in the 2.8mm guide post.
- Added separate index, middle, ring, and pinky contact widths and lever ratios.
- Added screw-fastened bottom covers, rear wire channels, strain-relief exit,
  replaceable TPU pads, adjustable mount plates, ±8° wedges, P0 fixture, finger
  surrogates, and M-grip integration preview.
- Replaced the original long side-key actuator with a short rotary cam and an
  independent vertical follower, so the EVQ switch receives axial load only.
- Added full-travel retention clearance, switch-terminal relief, cable grooves,
  measured 0.1/0.2/0.3mm U-shims, true 16mm depth slots, and near-±8° wedges.
- Made Variant A and Variant C functional comparators rather than disconnected
  concept solids; all three mechanisms now have exported neutral/L/C/R states.
- Added the four-cartridge carrier rail and its actual module-hole interface.
- Restricted STL to individual printable parts. Multi-solid assemblies are
  distributed as STEP/3MF; flattened STL files live only in the explicitly
  non-authoritative `renders/geometry_cache/` preview cache.
- Added exact B-rep mechanism/interface validation, welded 2-manifold STL/3MF
  audits, provenance hashes, real-state Blender renders, and reproducible
  Lalboard source/output locks plus Apache-2.0 attribution.

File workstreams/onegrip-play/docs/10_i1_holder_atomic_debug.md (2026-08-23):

# I1 holder pipeline 원자 분해 디버그 — 전 단계 PASS

- 일자 2026-08-19
- 대상: **INDEX_BTN_1 하나뿐.** I2/I3/I4/MIDDLE/RETAINER 미생성
- 체크포인트: 버전 `I1_atomic_debug_start` (`d6bd9efad2901e6f6103dfca`) — 작업 전 생성
- 결과: **TEST A~E 전부 PASS.** pre-union holder 파이프라인이 정상 동작함을 증명

---

## 0. 결론

> **CASE 6 — A~E 전부 성공.**
> pre-union holder 아키텍처(blank NEW BODY → blank만 hollow → 마지막 ADD UNION)는
> **정상 작동한다.** 직전 실행의 `INDEX_holders_preunion` 실패는 아키텍처 문제가 아니라
> **한 Feature 안에서 4버튼을 배열/다중 boolean 으로 동시에 처리한 로직**의 문제였다.

---

## 1. 사전 확인

| 항목 | 결과 |
|---|---|
| `JaD` Joystick_1 / `JfD` Joystick_2 | 존재, solid 16개 |
| regeneration 오류 | 0 |
| 체크포인트 버전 | `I1_atomic_debug_start` 생성 완료 |

### I1 축 재확인

승인 좌표 `(-22.224, -17.494, 9.000)` 에서 현재 표면을 재측정하면
**거리 4.003 mm, 법선 (+0.2739, +0.0703, −0.9592)** 가 나온다.
이는 오류가 아니라 **승인된 8 mm 개구부가 그 지점의 표면을 이미 제거했기 때문**이며,
측정된 면은 개구부의 측벽이다.

검증: 그 측벽 법선과 승인 축의 내적

```
(0.2739, 0.0703, −0.9592) · (−0.9291, −0.2385, −0.2828)
  = −0.25450 − 0.01677 + 0.27127 = −0.00000
```

**정확히 0 → 개구부가 승인 축에 정밀하게 정렬되어 있음이 확인된다.**
따라서 승인 축 `(-0.9291, -0.2385, -0.2828)` 을 그대로 사용했다.

(참고: 축에서 7 mm 떨어진 온전한 표면의 법선은 중심과 11~25° 차이가 난다.
I1 국소 곡률반경이 약 17 mm 로 작기 때문이며 정상이다.)

---

## 2. 디버그 구조

기존 `OneGrip_FingerButtons` 를 건드리지 않기 위해
**별도 Feature Studio** `OneGrip_I1_Debug` (`12c6873f8965a019b17f4e24`) 를 만들었다.
소스: `cad/OneGrip_I1_Debug.fs`

이번 디버그에서 **의도적으로 사용하지 않은 것**:

- `clipAtSplit` / X=0 클리핑 (I1 은 분할면에서 충분히 떨어져 있음)
- `concatenateArrays` 를 이용한 배열 UNION
- 다중 target REMOVE
- 여러 버튼 동시 boolean
- 쉘 2개를 한 op 에서 처리

**한 stage = 한 operation 계열**, body 는 blank 1개와 JfD 1개만 다뤘다.

blank 식별은 이름/인덱스가 아니라 좌표로 한다:
`blankPt = P − zA·6mm + xA·4.5mm` (holder 벽 안, seat/bore 어디에도 속하지 않는 지점).

### 깊이 체계 (전부 파라미터 종속)

```
쉘 벽 안쪽면   3.0
blank          2.8 … 12.5   (12.4 × 12.4)
front lip      2.8 … 3.8    (stem bore 4.5 만 관통)
switch seat    3.8 … 10.0   (스위치 3.8…9.8 + retainer_clearance 0.2)
rear 개방      10.0 … 14.5
```

---

## 3. TEST 결과

| TEST | Feature name | Feature ID | operation | state | solid before→after | 신규 body | 소멸 body | JaD | JfD |
|---|---|---|---|---|---|---|---|---|---|
| **A** | `DEBUG_I1_holder_blank` | `FfmaKp2OQZTimUt_15` | `fCuboid` + `opTransform` (NEW BODY) | **OK** | 16 → 17 | `RMFD` | — | 유지 | 유지 |
| **B** | `DEBUG_I1_switch_seat` | `FezJmTeZqE7iGiI_16` | seat 6.4×6.4 SUBTRACT (target = blank) | **OK** | 17 → 17 | 없음 | 없음 | 유지 | 유지 |
| **C** | `DEBUG_I1_open_rear` | `FVnIKEB4TpMO9oH_16` | rear 개방 SUBTRACT (target = blank) | **OK** | 17 → 17 | 없음 | 없음 | 유지 | 유지 |
| **D** | `DEBUG_I1_front_lip_bore` | `FpG3GYhbq9gpPMO_16` | stem bore 4.5 SUBTRACT (target = blank) | **OK** | 17 → 17 | 없음 | 없음 | 유지 | 유지 |
| **E** | `DEBUG_I1_union_JfD` | `FzbDmDsB3vjLdH6_16` | `qUnion([JfD, blank])` UNION | **OK** | 17 → 16 | 없음 | `RMFD` (JfD 로 흡수) | 유지 | **유지** |

**최초 실패 operation: 없음.**

### TEST E 직후 무결성 검사 (8개 항목 전부 통과)

| # | 항목 | 결과 |
|---|---|---|
| 1 | `JfD` partId 유지 | **YES** |
| 2 | `Joystick_2` body 개수 | **1개** (`JfD`) |
| 3 | duplicate `Joystick_2` | **없음** |
| 4 | body split | **없음** (신규 partId 0개) |
| 5 | `JaD` 정상 | **YES** (`Joystick_1` 1개) |
| 6 | assembly `Joystick_2 <1>` 참조 | **`JfD` 정상** |
| 7 | occurrences | **25 / 25** (변화 없음) |
| 8 | regeneration ERROR | **0** |

---

## 4. 최종 I1 holder geometry 실측

`evDistance` 로 버튼 축에서 가장 가까운 면까지의 거리를 측정:

| 깊이 | 측정값 (축→면) | 설계값 | 판정 |
|---|---|---|---|
| 3.3 mm (stem bore 구간) | **2.250 mm** | 4.5/2 = 2.25 | **정확 일치** |
| 6.0 mm (switch seat) | **3.147 mm** | 6.4/2 = 3.20 | 일치 (−0.053, 모서리 근접 측정 오차) |
| 11.0 mm (rear 개방) | **3.200 mm** | 6.4/2 = 3.20 | **정확 일치** |

- `Joystick_2` 부피 = **48.3755 cm³**
- solid body 수 = **16** (원래 상태 복귀 + holder 흡수)
- switch seat **6.4 × 6.4 mm** 확보
- front lip 4.5 mm 보어로 **front stop 형성** (스위치 6.0 mm 는 통과 불가)
- rear 완전 개방 → 내부 삽입 경로 및 배선 접근 확보

---

## 5. 직전 실행 실패의 원인 범위 축소

| 후보 | 판정 |
|---|---|
| pre-union 아키텍처 자체 | **무죄** — A~E 전부 PASS |
| `fCuboid` / `opTransform` blank 생성 | **무죄** (TEST A) |
| blank 대상 seat SUBTRACT | **무죄** (TEST B) |
| blank 대상 rear SUBTRACT | **무죄** (TEST C) |
| blank 대상 bore SUBTRACT | **무죄** (TEST D) |
| `qUnion([shell, body])` UNION | **무죄** (TEST E) |
| **`concatenateArrays` 배열 UNION** | **용의자 잔존** |
| **다중 target SUBTRACT (blank 여러 개)** | **용의자 잔존** |
| **`clipAtSplit` (I3/I4 전용)** | **용의자 잔존** |
| **한 Feature 안 4버튼 동시 처리** | **용의자 잔존** |

→ 다음 단계는 **버튼을 하나씩 추가하며 같은 원자 패턴을 반복**하는 것이다.
배열/다중 boolean 을 쓰지 말고, 버튼마다 별도 stage 또는 별도 Feature 로 처리하면
직전 실패를 재현하지 않는다.

---

## 6. 현재 문서 상태

| 항목 | 값 |
|---|---|
| 살아있는 커스텀 피처 | `INDEX_construction`, `INDEX_openings`, `INDEX_button_caps` + `DEBUG_I1_*` 5개 |
| `JaD` / `JfD` | 정상, split 0 |
| 기존 엄지 파트 10개 | 변화 없음 |
| **I1 holder** | **완성** (blank → seat → rear → lip → JfD 흡수) |
| I2 / I3 / I4 holder | 없음 |
| retainer | 없음 (지시대로 미생성) |
| regeneration | **오류 0** |

`DEBUG_I1_*` 5개 피처는 디버그용 이름이지만 **실제 형상을 만들고 있으므로 삭제하지 않았다.**
다음 실행에서 정식 파이프라인으로 통합할 때 이름을 정리하면 된다.

---

## 7. 다음 실행 권고

1. I2 를 같은 원자 패턴으로 추가 (blank → seat → rear → lip → union). 배열 사용 금지
2. 성공하면 I3 (여기서 `clipAtSplit` 을 **별도 stage 로 분리해** 단독 검증)
3. 그다음 I4 (JaD union)
4. 4개 완료 후 outer wall / switch clearance 재측정
5. 마지막에 retainer 단계

각 버튼 추가 직후 반드시 `JfD`/`JaD` partId·body 개수·assembly 참조를 확인한다.

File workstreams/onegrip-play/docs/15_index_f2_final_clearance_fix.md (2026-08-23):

# INDEX F2 최종 여유 수정 — 적용 및 실물 검증

- 일자 2026-08-19
- 승인 근거: `docs/14_index_f2_rebuild.md` (HOLD 3건 + 수정안 승인)
- 체크포인트 버전: **`F2_final_fix_start`** (`63e475448496b75aaeefdc24`)
- WRITE 대상: `OneGrip_Play_V1` did `a21e64f36bc61df760d4587c` / wid `ef6a7b3ccc45186203e4d2ca`
- **판정: §15 PASS 조건 11개 중 10개 직접 확인 PASS, 1개(regeneration 상태 직접 읽기)는
  rate limit 으로 간접 확인. 형상 결함 없음.**

---

## 0. 적용한 변경 — FeatureScript 3곳

피처를 추가·삭제하지 않았다. FS 소스만 고쳐 기존 인스턴스를 전부 재생성했다.

| # | 변경 | 이전 → 이후 |
|---|---|---|
| 1 | `IDX` 축 | F2 → **승인된 신규 축 4개** |
| 2 | `LIP_F2` | 1.5 → **2.3 mm** (스위치 앞면 축깊이 **5.3 mm**) |
| 3 | `blankTo` | `seatTo + retT(2.5)` → **`seatTo + 1.0`** |

3번으로 `#finger_retainer_thickness` 참조가 사라져 `retT` 가 미사용이 되었고,
**FeatureScript 는 미사용 지역변수를 에러로 처리**하므로 선언을 함께 제거했다.
(docs/14 §0.2 와 같은 유형. 이제 알려진 함정이다)

### 깊이 체계

```
쉘 벽             0 … 3.0      (n0 기준)
front trim 평면   n0 깊이 2.8   ← blank 앞면
스위치 앞면       축 깊이 5.3   (= 3.0 + 2.3)
스위치 뒷면       축 깊이 11.3
seat 끝           축 깊이 11.5
blank 뒤끝        축 깊이 12.5  (= seatTo + 1.0)
holder 단면       12.4 × 12.4
```

---

## 1. 최종 보고 (A ~ N)

### A. rebuild — **PASS**

| 항목 | 결과 |
|---|---|
| FS 컴파일 | OK (`idxHolderAtomic`) |
| solid body | **18개** (원본 14 + INDEX 캡 4). 예상 외 body **0개** |
| 시트 치수 | **4/4 전부 축에서 3.200 mm** = 정확히 6.4 × 6.4 (깊이 6.0 / 8.4 / 11.0 전부) |
| front trim | **4/4 적용.** 원본 외피 바깥 표본 289개 × 4 중 재료 **0개**, 돌출 **0.00 mm** |
| split clip | **4/4 적용** (아래 I 항목) |

### B. final axes

| | 축 (x, y, z) | 법선 편차 |
|---|---|---|
| **I1** | `(-0.851033, -0.500047, -0.160298)` | 17.21° |
| **I2** | `(-0.393870, -0.571110, -0.720208)` | 17.21° |
| **I3** | `(-0.069850, -0.997555, +0.002429)` | 17.21° |
| **I4** | `(+0.024161, -0.968017, -0.249718)` | 2.66° |

버튼 중심·Z=+9·피치 11·캡 8·6×6×6 스위치·3+1 ownership **전부 유지**.

### C. exact SAT minimum clearance — **1.3476 mm (조건 ≥ 1.20) PASS**

정확 분리축 정리(SAT). vertex-distance 미사용.

| 쌍 | 여유 |
|---|---|
| **I1-I2** | **+1.3476 mm** |
| I2-I3 | +1.3490 mm |
| I1-I3 | +4.7151 mm |
| I3-I4 | +3.9314 mm |
| I1-I4 | +13.3946 mm |
| I2-I4 | +10.0811 mm |

docs/14 예상 **1.348 mm** → 실제 **1.3476 mm**. 일치.

### D. pocket divider minimum — **0.8000 mm (조건 ≥ 0.80) PASS**

| 쌍 | 해석(포켓 OBB) | **실물 메시 광선상 재료** |
|---|---|---|
| **I1-I2** | 0.8000 mm | **0.8000 mm** (구간 [0.000, 0.800]) |
| **I2-I3** | 0.8000 mm | **0.8000 mm** (구간 [0.000, 0.800]) |
| I1-I3 | 4.2055 mm | — |
| I3-I4 | 3.5133 mm | — |

> **§10 요구 확인:** 경계값 0.800 이 메시 오차인지 실제 부족인지 구분했다.
> 두 포켓 최근접점을 잇는 선을 실물 tessellation 으로 관통 측정한 결과
> 재료 구간이 **정확히 0.800 mm** 로, 해석값과 완전히 같다.
> 포켓은 `fCuboid` 로 만든 정확한 박스이므로 이 값이 곧 B-rep 값이다. **부족분 없음.**

### E. actual seating — **4/4 YES**

평평한 쉘 가정을 쓰지 않고, **재생성된 실물 tessellation** 에 대해
각 버튼 축을 따라 6 × 6 단면(225개 표본)을 광선 관통시켜 측정했다.

| | required seating depth | first shell collision depth | seating feasible | min shell clearance |
|---|---|---|---|---|
| **I1** | **5.300 mm** | 5.300 mm (국소 −2.57, −2.57) | **YES** | 0.200 mm |
| **I2** | **5.300 mm** | 5.300 mm (국소 −2.57, +0.43) | **YES** | 0.200 mm |
| **I3** | **5.300 mm** | 5.300 mm (국소 −2.14, +3.00) | **YES** | 0.200 mm |
| **I4** | **5.300 mm** | 5.300 mm (국소 +2.57, −2.57) | **YES** | 0.200 mm |

**필요 깊이가 4개 전부 설계값 5.300 mm 와 정확히 같다.**
docs/14 HOLD-1 의 "개구부 바깥 쉘 벽이 앞모서리를 막는" 현상이 **완전히 사라졌다**
(이전: 필요 4.75 / 4.70 / 5.15 / 4.30 로 설계 4.5 를 초과했다).
min shell clearance 0.200 mm 는 설계 포켓 여유(6.4 − 6.0)/2 그대로다.

### F. opening / stem minimum clearance — **PASS**

기존 8 × 8 개구부를 **재생성 없이 그대로** 사용한다.

| | 4.5 mm 잠정 stem bore ↔ 개구부 벽 |
|---|---|
| I1 | 0.801 mm |
| **I2** | **0.730 mm** |
| I3 | 0.731 mm |
| I4 | 1.616 mm |

→ 최소 **0.730 mm > 0**. 통과 가능.

### G. cap travel — **PASS (외형 무수정)**

| | 캡 이동축(n0) ↔ 플런저축 | 행정 0.25 mm 당 측방 어긋남 |
|---|---|---|
| I1 / I2 / I3 | 17.21° | **0.0740 mm** |
| I4 | 2.66° | 0.0116 mm |

최대 **0.0740 mm < 캡 여유 0.20 mm**. **외부 캡 형상은 전혀 건드리지 않았다.**
남은 작업은 캡 밑면 접촉 pad 의 방향뿐이며, 이번 실행 범위가 아니다.

### H. screw B minimum 3D clearance — **2.990 mm (I4), 조건 ≥ 2.50 PASS**

단순 Z 비교가 아니라 유한 원기둥(⌀7, X ∈ [−6, +10]) ↔ 홀더 OBB 의 정확 3D 최소거리.

| | I1 | I2 | I3 | **I4** |
|---|---|---|---|---|
| 나사 B 3D 최소거리 | 4.466 | 5.058 | 4.726 | **2.990 mm** |

최소값 버튼 = **I4**. docs/14 예상 2.89 → 실제 **2.99 mm** (예상보다 양호).
`blankTo` 를 13.2 → 12.5 로 줄인 효과다.

### I. split ownership — **PASS**

| | 포켓 X 범위 | 분할면 벽 | 요구 | 판정 |
|---|---|---|---|---|
| I3 | −8.319 … **−1.500** | **1.500 mm** | X ≤ 0 | **PASS** |
| I4 | **+1.999** … +8.587 | **1.999 mm** | X ≥ 0 | **PASS** |

holder blank 은 여전히 분할면을 넘으므로(I3 → +1.56, I4 → −1.04) `SPLITCLIP` 이 필요하며,
**실물에서 적용 확인**: `JfD` 안의 X>0 영역 표본 253개 중 재료 **0개**,
`JaD` 안의 X<0 영역 표본 176개 중 재료 **0개**.

기존 결과를 재사용하지 않고 **신규 geometry 로 다시 실측**했다.

### J. JaD / JfD — **PASS**

| 항목 | 결과 |
|---|---|
| `JaD` = Joystick_1 | 유지, **body 1개** |
| `JfD` = Joystick_2 | 유지, **body 1개** |
| body split | **0** |
| duplicate shell | **0** |
| 예상 외 신규 body | **0** |

### K. assembly / regeneration

| 항목 | 결과 |
|---|---|
| `Joystick` occurrences / instances | **25 / 25** |
| `Joystick_1` → `JaD`, `Joystick_2` → `JfD` | **정상** |
| 삭제된 plug 참조 (dangling) | **0개** |
| **regeneration ERROR 직접 읽기** | **불가 — `/features` GET 429 (Retry-After 6,174 s ≈ 1.7 h)** |

> **간접 확인:** 모든 stage 인스턴스의 산출물이 정상이다 —
> blank 4개 존재, 시트 4/4 정확히 6.4×6.4, front trim 4/4 적용(돌출 0.00),
> split clip 4/4 적용, union 4/4 완료(별도 body 잔존 0), RETAINER no-op 4/4(plug 0개),
> body 수 18개로 예상과 정확히 일치, assembly 무결.
> **어느 피처가 ERROR 였다면 이 중 하나는 반드시 어긋난다.** 형상 결함은 없다.
> 다만 `featureStates` 를 직접 읽은 것은 아니므로, **rate limit 해제 후 확인 예정**이다.

### L. front lip actual applied value — **2.3 mm**

```
FeatureScript:  const LIP_F2 = 2.3 * millimeter;
결과 스위치 앞면 축깊이 = SHELL_WALL(3.0) + 2.3 = 5.3 mm
```
실물 측정에서 스위치가 정확히 5.300 mm 에 착좌함을 확인했다(§E).
**이 값이 현재 형상의 source of truth 다.**

### M. stale tree-variable 상태 — **TECHNICAL DEBT (기록됨)**

| | 값 | 상태 |
|---|---|---|
| FS 상수 `LIP_F2` | **2.3 mm** | **실제 형상 기준 (source of truth)** |
| 트리 변수 `#finger_switch_front_lip` | 0.8 mm | **사문(死文). 아무 데서도 읽히지 않음** |

FS 소스 상단에 `===== TECHNICAL DEBT / TODO =====` 블록으로 명시했다.
트리 변수를 수정하려면 그 featureId 가 필요하고 그러려면 `/features` GET 이 필요한데
429 상태다. **rate limit 해제 후 트리 변수를 2.3 으로 바꾸고 `getVariable` 로 되돌린다.**
**트리의 0.8 mm 를 기준으로 삼지 말 것.**

### N. shared retainer 진행 — **GO (단, K 의 formal 확인을 선행)**

§15 PASS 조건 대조:

| # | 조건 | 결과 |
|---|---|---|
| 1 | switch SAT ≥ 1.20 mm | **1.3476** PASS |
| 2 | pocket divider ≥ 0.80 mm | **0.8000** PASS |
| 3 | screw clearance ≥ 2.50 mm | **2.990** PASS |
| 4 | actual seating 4/4 YES | **4/4 YES** PASS |
| 5 | 기존 8×8 openings 사용 가능 | **PASS** (최소 0.730 mm) |
| 6 | cap exterior unchanged | **PASS** (무수정) |
| 7 | 3+1 ownership 유지 | **PASS** |
| 8 | JaD/JfD 유지 | **PASS** |
| 9 | assembly 25/25 | **PASS** |
| 10 | regeneration ERROR 0 | **간접 PASS** (직접 읽기 429) |
| 11 | old twist-lock plug 재생성 없음 | **PASS** (`RWID`/`RmID`/`R2ID`/`RGJD` 부재) |

→ **실패 항목 0건.** 10번만 형식적 확인이 남았다.
`/features` 가 열리는 즉시 `featureStates` 를 읽어 확정한 뒤 retainer 로 넘어간다.

**이번 실행에서는 §16 지시대로 shared retainer 를 만들지 않고 여기서 멈춘다.**

---

## 2. 다음 단계

1. (rate limit 해제 후) `featureStates` 확인 → §15-10 확정
2. (같은 시점) `#finger_switch_front_lip` 트리 변수를 2.3 으로 동기화하고
   FS 를 `getVariable` 로 복귀 + RETAINER no-op 스텁 4개 삭제 + 피처 이름 정리
3. **I1/I2/I3 공용 후면 retaining plate 설계**
   — 뒷면 사잇각이 34~56° 로 벌어져 평판 불가. **pad 3개를 각각 다른 높이·각도로 설계한 1장** (docs/14 §6-L)
4. I4 별도 소형 retainer
5. INDEX 최종 SUCCESS 후 MIDDLE (free-axis minimax, docs/13 §13-K 규칙)

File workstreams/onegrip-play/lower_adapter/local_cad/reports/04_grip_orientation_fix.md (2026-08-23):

# OneGrip 방향(front/back) 교정

**결과: 방향 불변량 10 PASS / 0 FAIL, 기계 재검증 22 PASS / 0 FAIL.**
Onshape API 호출 0건. STEP 레퍼런스 3개 무수정. 하부 형상 변경 0건.

---

## 1. ROOT CAUSE

**변환 부호 오류가 아니다. 어셈블리가 고른 물림 방향이 반대였다.**

후보 A(assembly → grip 변환)와 B/C(OneGrip 인스턴스 / post 축 모호성)를 형상으로 갈랐다.

### A는 배제됨 — assembly → grip 변환은 옳다

`align_reference.py` 1단계가 스톡 Base 의 회전을 **하드코딩된 가정**으로 고르고 있었다:

```
if ts < 0:                       # 그립 프레임에서 꼬리는 -Y
```

캐리어 포켓 바닥면은 100.600 × 100.600 (Base **본체**만)이라 회전을 확정하지 못한다.
회전을 실제로 확정하는 것은 **하우징의 꼬리 슬롯**이다. 두 후보를 실제 부울로 채점했다:

| 후보 | Base 꼬리 | 하우징 간섭 | 캐리어 간섭 |
|---|---|---|---|
| Rz(0) | +Y | **2,621.78 mm³** | 756.91 mm³ |
| **Rz(180)** | −Y | **0.00 mm³** | 0.00 mm³ |

Rz(180)만 슬롯에 들어간다 → 현재 변환이 옳다. 스톡 Base·전장·캐리어 정합은 건드릴 이유가 없다.

### C가 원인 — post 물림의 2-fold 모호성

부착축을 **두 부품에서 독립적으로** 얻었고 정확히 일치한다:

| 출처 | 법선 |
|---|---|
| OneGrip 착좌면 (면적 1,958.16 × 2) | (+0.007857, −0.097373, −0.995217) |
| Pitch 상단면 (면적 445.05) | (−0.007857, +0.097373, +0.995217) |

→ 부착축 **a = (−0.007857, +0.097373, +0.995217)**, grip +Z 에서 **5.6061°**
(= 어셈블리 스냅샷의 Pitch 편향 5.606°).

소켓 보어 내벽 4면의 평면식을 풀어 단면을 구했다: **21.0720 × 25.6720 mm 직사각형**
(문서값과 일치). **직사각형은 축 둘레 180°에 대해 자기 자신으로 간다** →
post 물림이 두 방향 모두 기계적으로 성립한다. 어셈블리 STEP 이 그 중 반대쪽을 담고 있었다.

### 축 통과점

축은 **짐벌 피벗을 지난다**. 측정된 통과점 p0 = (−0.369139, 31.844001, −68.102584) 는
피벗 (0, 27.275842, −114.860854) 을 지나는 직선에서 **0.0068 mm** 벗어나며,
축방향 거리는 **46.982 mm** 다 (CLAUDE.md 의 "플랜지면 아래 46.98mm" 와 일치).

9자세 캐시의 `Pitch` 점군 Kabsch 로 교차검증했다 — **전 자세에서 피벗 이동 0.0000 mm**,
중립 자세 축 = **(0, 0, 1) 정확**, Kabsch 잔차 ≤ 3.4e-12 mm.

**교정 = 축 (a, p0) 둘레 180° 강체 회전, OneGrip 상부에만 적용.**

---

## 2. 방향 불변량 (신규)

`build123d/grip_orientation.py` + `fix_grip_orientation.py`.

- **`GRIP_FORWARD_VECTOR`** — 손잡이 상단이 기우는 수평 방향. 그립 샤프트 주축(PCA)을
  데크 평면에 투영. SIDE 프리뷰에서 눈에 보이는 바로 그 방향이고, 비대칭이라 180°를 구분한다.
- **`WRIST_SUPPORT_DIRECTION`** — 하우징에서 유도. (ERGO − CORE) 재료의 도심 − 코어 도심,
  XY 투영. 상수를 손으로 넣지 않는다.
- **게이트: `dot(GRIP_FORWARD, WRIST_SUPPORT) < 0`**

```
WRIST_SUPPORT_DIRECTION       = (-0.018424, -0.999830, +0.000000)

GRIP_FORWARD_VECTOR  before   = (+0.194424, -0.980918, +0.000000)
GRIP_FORWARD_VECTOR  after    = (-0.146334, +0.989235, +0.000000)

(교차검증) 엄지패널 before      = (+0.020375, +0.999792, +0.000000)
(교차검증) 엄지패널 after       = (-0.349631, -0.936887, +0.000000)

dot  before = +0.977169   (사이각  12.267 deg)   -> FAIL (반전 상태)
dot  after  = -0.986371   (사이각 170.530 deg)   -> PASS
```

**이 검사는 20°/90°가 전부 통과하는 상태에서 반전을 잡아낸다.** 그게 목적이다.

### 방향 불변량 10 PASS / 0 FAIL

| 검사 | 결과 |
|---|---|
| 소켓 보어 = 21.072 × 25.672 | PASS |
| 착좌면 불변 (법선 0.00e+00 deg, 오프셋 1.42e-14 mm) | PASS |
| 소켓 보어가 자기 자신으로 (축 이동 **2.03e-14 mm**) | PASS |
| 회전 후 코어·캐리어 간섭 증가 없음 (0 → 0) | PASS |
| 회전 후 스톡 짐벌 간섭 증가 없음 (0 → 0) | PASS |
| 현재 방향이 반전 상태임을 검출 | PASS |
| 교정 후 방향 불변량 | PASS |
| 기준면 20.000000000° / 중립축 ⟂ / 하부 무변경 | PASS |

---

## 3. BEFORE / AFTER 와 보존 항목

| 항목 | BEFORE | AFTER |
|---|---|---|
| GRIP_FORWARD | (+0.194424, −0.980918, 0) | (−0.146334, +0.989235, 0) |
| dot(GRIP, WRIST) | +0.977169 | −0.986371 |
| 기준면 vs 수평 | 20.000000000° | **20.000000000°** |
| 중립축 ⟂ 기준면 | 90° | **90°** |
| HAND_REF | (−8.960946, −13.645934, −6.0) | **동일** |
| deck → HAND_REF | 55.8785 | **55.8785** |
| ground → HAND_REF | 161.0208 | **161.0208** |
| 짐벌 피벗 | (0, 27.275842, −114.860854) | **동일 (전 자세 이동 0.0000)** |
| 스톡 Base ↔ 캐리어 | 검증 상태 | **무변경 (부울 0/0)** |
| 스톡 돌출 | 0.0000 mm | **0.0000 mm** |
| 캐리어 −Z 인출 0–100 mm | 무충돌 | **무충돌** |
| 하우징 W/L/H | 133.600 / 197.243 / 139.857 | **동일** |

---

## 4. 모션 검사 — **TRANSFORMED / CACHED ENVELOPE**

캐시 `motion_configs.npz` 에는 OneGrip 상부가 들어 있다 (덱 위 점 2,468,801개:
`Joystick_1/2`, `Backplate`, `HW504_B ×2`, `Small_joystick_attachment`).
따라서 **그대로 재사용하지 않았다.**

자세마다 그 자세의 부착축 (피벗, B_k·ẑ) 둘레로 **그립 점만** 회전시켜
`motion_configs_gripfix.npz` 를 새로 만들었다 (`fix_motion_envelope.py`).

| 자세 | Kabsch 잔차 | 피벗 고정 | 축 각도 |
|---|---|---|---|
| neutral | 2.8e-14 | 0.0000 | 0.0000° |
| X±10 / Y±10 | ≤1.6e-12 | 0.0000 | 10.0000° |
| 코너 4 | ≤2.0e-12 | 0.0000 | 14.1060° |

회전된 점 **2,567,430**개. **스톡 이동부 점군은 완전 무변화** (배열 동일성 확인).

결과: 9자세 전부 `0 / 20,130 점`. **이 검사는 DIRECT BREP 이 아니라 TRANSFORMED/CACHED 다.**
어셈블리 스냅샷 한 자세에 대한 검사는 DIRECT BREP 이고, 신규 간섭 −0.000000 mm³ 다
(전체 138.2772 = 동결 코어가 이미 갖고 있던 나사 머리 4개분, W2 기여 0).

---

## 5. 프리뷰

```
lower_adapter/local_cad/preview/SIDE.png
lower_adapter/local_cad/preview/ISOMETRIC.png
lower_adapter/local_cad/preview/TOP.png
```
(FRONT / BOTTOM / CUTAWAY 도 같이 갱신됨)

하우징·스톡 짐벌은 이전 프리뷰와 같은 자리이고 손잡이만 반대로 향한다.

## 6. 변경된 파일 (로컬 변환 로직만)

```
build123d/grip_orientation.py     신규 — 축 유도 + 방향 불변량
build123d/fix_grip_orientation.py 신규 — 교정 + 10개 검사
build123d/fix_motion_envelope.py  신규 — 자세별 포락선 변환
build123d/assembly_preview.py     Joystick 자식에만 교정 적용
build123d/verify_geometry.py      교정 어셈블리 + 변환 포락선 사용
reports/03_grip_orientation.json  수치 기록
cad_dump/motion_configs_gripfix.npz  신규 캐시 (33.1 MB)
```

STEP 레퍼런스 3개와 `ERGO_HOUSING_W2.step` 형상은 **수정하지 않았다.**

## 7. STOP

지시대로 여기서 멈춘다. 손목 연장 / 외피 재설계 / 필렛 변경은 착수하지 않았다.

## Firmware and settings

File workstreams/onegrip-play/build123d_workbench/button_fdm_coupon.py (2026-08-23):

"""Build the independent ITS-1105 button FDM test coupon.

This module is deliberately self-contained.  It does not import, edit, or
export any OneGrip production geometry.  The only outputs are a standalone
print-layout STEP/STL and the coupon test document requested for this study.

V2 replaces the rejected side-loading station with a support-free, top-loaded
switch cradle and a separately printed guide deck.  The change is based on the
physical P6.30 result and a read-only audit of the original open-source
``PushBtn`` reference.  No reference B-rep is consumed by this generator.

Default units are millimetres.  Measured switch values can be changed either
in ``CouponConfig`` below or with the command-line overrides shown by
``python -m build123d_workbench.button_fdm_coupon --help``.
"""

from __future__ import annotations

import argparse
import copy
from dataclasses import dataclass, replace
import hashlib
from pathlib import Path
from typing import Iterable

from build123d import (
    Align,
    Axis,
    Box,
    Compound,
    Cone,
    Cylinder,
    Location,
    Shape,
    Vector,
    export_step,
    export_stl,
)


ROOT = Path(__file__).resolve().parents[1]
OUT_DIR = ROOT / "build123d_workbench" / "out" / "button_fdm_coupon"
STEP_PATH = OUT_DIR / "BUTTON_FDM_TEST_COUPON.step"
STL_PATH = OUT_DIR / "BUTTON_FDM_TEST_COUPON.stl"
DOC_PATH = ROOT / "docs" / "button_fdm_coupon_test.md"


@dataclass(frozen=True)
class CouponConfig:
    """Editable hardware and test parameters.

    ``measured_body_x_mm`` and ``measured_body_y_mm`` are the physical-sample
    dimensions.  ``pocket_seed_mm`` and ``pocket_offsets_mm`` control the
    square pocket coupon independently, so a new measured lot does not require
    editing construction code.
    """

    measured_body_x_mm: float = 6.12
    measured_body_y_mm: float = 6.05
    housing_height_mm: float = 3.56
    actuator_diameter_mm: float = 3.35
    actuator_projection_mm: float = 2.44

    # Physical P1S result: P6.30 accepts the user's switch lot with a close fit.
    mechanism_pocket_mm: float = 6.30

    # Read-only open-source PushBtn detail envelope.  These are explicit
    # parameters because the old coupon omitted both features.  The four front
    # posts are Ø1.00 at (±2.25, ±2.25); the formed leads occupy about 7.566 mm
    # across the body and extend about 3.52 mm behind it.
    corner_post_diameter_mm: float = 1.00
    corner_post_offset_mm: float = 2.25
    corner_post_height_mm: float = 0.50
    terminal_outer_span_mm: float = 7.566
    terminal_rear_reach_mm: float = 3.52
    pin_clearance_depth_mm: float = 4.20

    pocket_seed_mm: float = 6.40
    pocket_offsets_mm: tuple[float, ...] = (-0.10, -0.05, 0.0, 0.05, 0.10)

    cap_tail_diameter_mm: float = 4.50
    guide_seed_mm: float = 4.80
    guide_offsets_mm: tuple[float, ...] = (-0.10, -0.05, 0.0, 0.05, 0.10)
    contact_diameter_mm: float = 3.00
    hard_stop_travel_mm: float = 0.350

    minimum_structural_wall_mm: float = 1.20

    @property
    def pocket_variants_mm(self) -> tuple[float, ...]:
        return tuple(round(self.pocket_seed_mm + value, 2) for value in self.pocket_offsets_mm)

    @property
    def guide_variants_mm(self) -> tuple[float, ...]:
        return tuple(round(self.guide_seed_mm + value, 2) for value in self.guide_offsets_mm)


# Print-layout dimensions.  The coupon body is one connected base; the guide
# deck and five caps are intentionally separate bodies in the same STL/STEP.
BASE_X_MM = 82.0
BASE_Y_MM = 52.0
BASE_Z_MM = 2.40
STATION_X_MM = (11.0, 26.0, 41.0, 56.0, 71.0)
POCKET_ROW_Y_MM = 14.0
GUIDE_ROW_Y_MM = 39.0
DECK_PRINT_ROW_Y_MM = 59.0
CAP_PRINT_ROW_Y_MM = 70.0
CLIP_PRINT_ROW_Y_MM = 80.0

# Pocket-only fit cells.
FIT_CELL_OUTER_MM = 10.0
FIT_CELL_HEIGHT_MM = 5.20

# V2 complete mechanism cell.  Four open corner columns locate the 6.30 mm
# housing while leaving every terminal side and the full uncut lead length
# exposed.  A central pedestal provides the rear reaction support.
CRADLE_OUTER_MM = 10.60
CENTRAL_SUPPORT_MM = 4.00
SHOULDER_CAVITY_MM = 6.80
SHOULDER_SIZE_MM = 6.50
SHOULDER_HEIGHT_MM = 1.20
RETENTION_GROOVE_DIAMETER_MM = 3.50
RETENTION_CLIP_BORE_MM = 3.70
RETENTION_CLIP_SLOT_MM = 3.80
FRONT_RETENTION_LIP_MM = 1.20
CAP_PAD_MM = 8.40
CAP_PAD_HEIGHT_MM = 2.00
CAP_TAIL_OVERLAP_MM = 0.10
CONTACT_HEIGHT_MM = 0.25
CONTACT_TAIL_GAP_MM = 0.15

# The cap coordinates below are relative to the free actuator top.  At rest,
# the shoulder touches the front retention lip.  Its lower face remains
# exactly 0.350 mm above the independent structural rear stop.
SHOULDER_BOTTOM_REL_MM = 1.25
SHOULDER_TOP_REL_MM = SHOULDER_BOTTOM_REL_MM + SHOULDER_HEIGHT_MM
FRONT_LIP_TOP_REL_MM = SHOULDER_TOP_REL_MM + FRONT_RETENTION_LIP_MM
TAIL_BOTTOM_REL_MM = CONTACT_TAIL_GAP_MM

# The common guide deck is printed assembled-top-face-down.  Its five shoulder
# cavities therefore open upward during printing and create no bridge/roof.
DECK_X_MM = BASE_X_MM
DECK_Y_MM = CRADLE_OUTER_MM
RETAINER_BOSS_DIAMETER_MM = 5.60
RETAINER_PILOT_DIAMETER_MM = 2.80
RETAINER_CLEARANCE_DIAMETER_MM = 3.40
RETAINER_X_MM = (3.0, BASE_X_MM - 3.0)

# Raised, code-native labels avoid system-font and slicer-font dependencies.
LABEL_HEIGHT_MM = 0.45
LABEL_STROKE_MM = 0.42
LABEL_DIGIT_W_MM = 1.45
LABEL_DIGIT_H_MM = 2.45
LABEL_ADVANCE_MM = 1.82


SEGMENTS = {
    "0": "abcdef",
    "1": "bc",
    "2": "abdeg",
    "3": "abcdg",
    "4": "bcfg",
    "5": "acdfg",
    "6": "acdefg",
    "7": "abc",
    "8": "abcdefg",
    "9": "abcdfg",
    # Block-style row prefixes, made from the same robust rectangular strokes.
    "G": "acdef",
    "P": "abefg",
}


def moved(shape: Shape, x: float = 0.0, y: float = 0.0, z: float = 0.0) -> Shape:
    return shape.moved(Location(Vector(float(x), float(y), float(z))))


def fuse_all(shapes: Iterable[Shape], label: str) -> Shape:
    rows = list(shapes)
    if not rows:
        raise ValueError(f"No shapes supplied for {label}")
    result = rows[0]
    for shape in rows[1:]:
        result = result.fuse(shape)
    result = result.clean()
    result.label = label
    return result


def subtract_all(shape: Shape, cutters: Iterable[Shape], label: str) -> Shape:
    result = shape
    for cutter in cutters:
        result = result - cutter
    result = result.clean()
    result.label = label
    return result


def raised_label(text: str, x_center: float, y_center: float, z_base: float) -> list[Shape]:
    """Return a raised seven-segment/block label as printable solids."""

    advances = [0.56 if char == "." else LABEL_ADVANCE_MM for char in text]
    total = sum(advances) - 0.18
    cursor = x_center - total / 2.0
    rows: list[Shape] = []
    for char, advance in zip(text, advances):
        if char == ".":
            rows.append(
                moved(
                    Box(
                        LABEL_STROKE_MM,
                        LABEL_STROKE_MM,
                        LABEL_HEIGHT_MM,
                        align=(Align.CENTER, Align.CENTER, Align.MIN),
                    ),
                    cursor + LABEL_STROKE_MM / 2.0,
                    y_center - LABEL_DIGIT_H_MM / 2.0 + LABEL_STROKE_MM / 2.0,
                    z_base,
                )
            )
            cursor += advance
            continue

        active = SEGMENTS[char]
        cx = cursor + LABEL_DIGIT_W_MM / 2.0
        cy = y_center
        horizontal = LABEL_DIGIT_W_MM - LABEL_STROKE_MM
        vertical = LABEL_DIGIT_H_MM / 2.0 - LABEL_STROKE_MM
        definitions = {
            "a": (horizontal, LABEL_STROKE_MM, cx, cy + LABEL_DIGIT_H_MM / 2.0 - LABEL_STROKE_MM / 2.0),
            "g": (horizontal, LABEL_STROKE_MM, cx, cy),
            "d": (horizontal, LABEL_STROKE_MM, cx, cy - LABEL_DIGIT_H_MM / 2.0 + LABEL_STROKE_MM / 2.0),
            "f": (LABEL_STROKE_MM, vertical, cursor + LABEL_STROKE_MM / 2.0, cy + LABEL_DIGIT_H_MM / 4.0),
            "b": (LABEL_STROKE_MM, vertical, cursor + LABEL_DIGIT_W_MM - LABEL_STROKE_MM / 2.0, cy + LABEL_DIGIT_H_MM / 4.0),
            "e": (LABEL_STROKE_MM, vertical, cursor + LABEL_STROKE_MM / 2.0, cy - LABEL_DIGIT_H_MM / 4.0),
            "c": (LABEL_STROKE_MM, vertical, cursor + LABEL_DIGIT_W_MM - LABEL_STROKE_MM / 2.0, cy - LABEL_DIGIT_H_MM / 4.0),
        }
        for segment in active:
            width, depth, sx, sy = definitions[segment]
            rows.append(
                moved(
                    Box(width, depth, LABEL_HEIGHT_MM, align=(Align.CENTER, Align.CENTER, Align.MIN)),
                    sx,
                    sy,
                    z_base,
                )
            )
        cursor += advance
    return rows


def seed_label_frame(x_center: float, y_center: float, z_base: float) -> list[Shape]:
    width, depth, stroke = 10.6, 3.65, 0.35
    return [
        moved(Box(width, stroke, LABEL_HEIGHT_MM, align=(Align.CENTER, Align.CENTER, Align.MIN)), x_center, y_center + depth / 2.0, z_base),
        moved(Box(width, stroke, LABEL_HEIGHT_MM, align=(Align.CENTER, Align.CENTER, Align.MIN)), x_center, y_center - depth / 2.0, z_base),
        moved(Box(stroke, depth, LABEL_HEIGHT_MM, align=(Align.CENTER, Align.CENTER, Align.MIN)), x_center - width / 2.0, y_center, z_base),
        moved(Box(stroke, depth, LABEL_HEIGHT_MM, align=(Align.CENTER, Align.CENTER, Align.MIN)), x_center + width / 2.0, y_center, z_base),
    ]


def build_cap(config: CouponConfig) -> Shape:
    """Build one removable cap in coordinates relative to actuator free top.

    The Ø4.50 guide tail stays solid except for a local Ø3.50 retention groove.
    A separate flat C-clip occupies that groove after the cap has passed through
    the uninterrupted round guide bore.
    """

    # The pad clears the guide roof throughout the complete 0.350 mm motion.
    # Retention and the hard stop act on the internal shoulder, not the pad.
    pad_bottom = FRONT_LIP_TOP_REL_MM + config.hard_stop_travel_mm
    tail_top = pad_bottom + CAP_TAIL_OVERLAP_MM
    contact = Cylinder(
        config.contact_diameter_mm / 2.0,
        CONTACT_HEIGHT_MM,
        align=(Align.CENTER, Align.CENTER, Align.MIN),
    )
    lower_tail = moved(
        Cylinder(
            config.cap_tail_diameter_mm / 2.0,
            SHOULDER_BOTTOM_REL_MM - 0.50 - TAIL_BOTTOM_REL_MM,
            align=(Align.CENTER, Align.CENTER, Align.MIN),
        ),
        z=TAIL_BOTTOM_REL_MM,
    )
    print_safe_groove_ramp = moved(
        Cone(
            config.cap_tail_diameter_mm / 2.0,
            RETENTION_GROOVE_DIAMETER_MM / 2.0,
            0.50,
            align=(Align.CENTER, Align.CENTER, Align.MIN),
        ),
        z=SHOULDER_BOTTOM_REL_MM - 0.50,
    )
    groove_core = moved(
        Cylinder(
            RETENTION_GROOVE_DIAMETER_MM / 2.0,
            SHOULDER_HEIGHT_MM,
            align=(Align.CENTER, Align.CENTER, Align.MIN),
        ),
        z=SHOULDER_BOTTOM_REL_MM,
    )
    upper_tail = moved(
        Cylinder(
            config.cap_tail_diameter_mm / 2.0,
            tail_top - SHOULDER_TOP_REL_MM,
            align=(Align.CENTER, Align.CENTER, Align.MIN),
        ),
        z=SHOULDER_TOP_REL_MM,
    )
    pad = moved(
        Box(CAP_PAD_MM, CAP_PAD_MM, CAP_PAD_HEIGHT_MM, align=(Align.CENTER, Align.CENTER, Align.MIN)),
        z=pad_bottom,
    )
    cap = fuse_all(
        (contact, lower_tail, print_safe_groove_ramp, groove_core, upper_tail, pad),
        "BUTTON_FDM_REMOVABLE_CAP",
    )
    if len(cap.solids()) != 1:
        raise RuntimeError(f"Cap must be one solid, got {len(cap.solids())}")
    return cap


def build_retention_clip() -> Shape:
    """Build one flat C-clip for the cap's Ø3.50 retention groove."""

    blank = Cylinder(
        SHOULDER_SIZE_MM / 2.0,
        SHOULDER_HEIGHT_MM,
        align=(Align.CENTER, Align.CENTER, Align.MIN),
    )
    bore = moved(
        Cylinder(
            RETENTION_CLIP_BORE_MM / 2.0,
            SHOULDER_HEIGHT_MM + 0.20,
            align=(Align.CENTER, Align.CENTER, Align.MIN),
        ),
        z=-0.10,
    )
    radial_slot = moved(
        Box(
            SHOULDER_SIZE_MM / 2.0 + 0.20,
            RETENTION_CLIP_SLOT_MM,
            SHOULDER_HEIGHT_MM + 0.20,
            align=(Align.MIN, Align.CENTER, Align.MIN),
        ),
        0.0,
        0.0,
        -0.10,
    )
    clip = subtract_all(blank, (bore, radial_slot), "BUTTON_FDM_CAP_RETENTION_C_CLIP")
    if len(clip.solids()) != 1:
        raise RuntimeError(f"Retention clip must be one solid, got {len(clip.solids())}")
    return clip


def mechanism_levels(config: CouponConfig) -> dict[str, float]:
    switch_rear = BASE_Z_MM + config.pin_clearance_depth_mm
    switch_front = switch_rear + config.housing_height_mm
    actuator_top = switch_front + config.actuator_projection_mm
    deck_bottom = actuator_top + SHOULDER_BOTTOM_REL_MM - config.hard_stop_travel_mm
    cavity_height = SHOULDER_HEIGHT_MM + config.hard_stop_travel_mm
    return {
        "switchRear": switch_rear,
        "switchFront": switch_front,
        "actuatorTop": actuator_top,
        "deckBottom": deck_bottom,
        "deckCavityHeight": cavity_height,
        "deckTop": deck_bottom + cavity_height + FRONT_RETENTION_LIP_MM,
        "shoulderBottom": actuator_top + SHOULDER_BOTTOM_REL_MM,
        "shoulderTop": actuator_top + SHOULDER_TOP_REL_MM,
        "frontLipTop": actuator_top + FRONT_LIP_TOP_REL_MM,
    }


def build_cradle_station(config: CouponConfig, x: float, y: float) -> Shape:
    """Build one fully open, top-loading switch cradle.

    Four corner columns locate the square housing.  Their cardinal gaps admit
    the complete formed lead envelope in either 90-degree orientation.  A
    central pedestal supports the rear housing face without touching leads.
    There is no switch-pocket roof and therefore no hidden bridge.
    """

    levels = mechanism_levels(config)
    bottom = BASE_Z_MM - 0.10
    support = moved(
        Box(
            CENTRAL_SUPPORT_MM,
            CENTRAL_SUPPORT_MM,
            levels["switchRear"] - bottom,
            align=(Align.CENTER, Align.CENTER, Align.MIN),
        ),
        x,
        y,
        bottom,
    )

    locator_width = (CRADLE_OUTER_MM - config.mechanism_pocket_mm) / 2.0
    locator_offset = config.mechanism_pocket_mm / 2.0 + locator_width / 2.0
    locator_height = levels["deckBottom"] - bottom
    columns = [
        moved(
            Box(locator_width, locator_width, locator_height, align=(Align.CENTER, Align.CENTER, Align.MIN)),
            x + sx * locator_offset,
            y + sy * locator_offset,
            bottom,
        )
        for sx in (-1.0, 1.0)
        for sy in (-1.0, 1.0)
    ]
    cradle = fuse_all((support, *columns), "OPEN_TOP_SWITCH_CRADLE")
    return cradle


def build_guide_deck(config: CouponConfig) -> Shape:
    """Build the common guide/retention/hard-stop deck in assembled pose."""

    levels = mechanism_levels(config)
    deck_height = levels["deckTop"] - levels["deckBottom"]
    deck = moved(
        Box(DECK_X_MM, DECK_Y_MM, deck_height, align=(Align.MIN, Align.CENTER, Align.MIN)),
        0.0,
        GUIDE_ROW_Y_MM,
        levels["deckBottom"],
    )
    cutters: list[Shape] = []
    for x, guide in zip(STATION_X_MM, config.guide_variants_mm):
        cutters.append(
            moved(
                Box(
                    SHOULDER_CAVITY_MM,
                    SHOULDER_CAVITY_MM,
                    levels["deckCavityHeight"] + 0.10,
                    align=(Align.CENTER, Align.CENTER, Align.MIN),
                ),
                x,
                GUIDE_ROW_Y_MM,
                levels["deckBottom"] - 0.05,
            )
        )
        cutters.append(
            moved(
                Cylinder(
                    guide / 2.0,
                    deck_height + 0.20,
                    align=(Align.CENTER, Align.CENTER, Align.MIN),
                ),
                x,
                GUIDE_ROW_Y_MM,
                levels["deckBottom"] - 0.10,
            )
        )
    for x in RETAINER_X_MM:
        cutters.append(
            moved(
                Cylinder(
                    RETAINER_CLEARANCE_DIAMETER_MM / 2.0,
                    deck_height + 0.20,
                    align=(Align.CENTER, Align.CENTER, Align.MIN),
                ),
                x,
                GUIDE_ROW_Y_MM,
                levels["deckBottom"] - 0.10,
            )
        )
    return subtract_all(deck, cutters, "REMOVABLE_FULL_BORE_GUIDE_DECK")


def build_pocket_fit_cell(pocket: float, x: float, y: float) -> Shape:
    tower = moved(
        Box(FIT_CELL_OUTER_MM, FIT_CELL_OUTER_MM, FIT_CELL_HEIGHT_MM, align=(Align.CENTER, Align.CENTER, Align.MIN)),
        x,
        y,
        BASE_Z_MM - 0.10,
    )
    through = moved(
        Box(pocket, pocket, BASE_Z_MM + FIT_CELL_HEIGHT_MM + 0.40, align=(Align.CENTER, Align.CENTER, Align.MIN)),
        x,
        y,
        -0.10,
    )
    cell = (tower - through).clean()
    cell.label = f"POCKET_{pocket:.2f}_FIT_CELL"
    return cell


def place_on_bed(shape: Shape, x: float, y: float) -> Shape:
    # build123d locations can retain shared label metadata when the same source
    # shape is placed repeatedly.  Copy first so STEP child names stay unique.
    shape = copy.copy(shape)
    bbox = shape.bounding_box()
    return moved(
        shape,
        x - (float(bbox.min.X) + float(bbox.max.X)) / 2.0,
        y - (float(bbox.min.Y) + float(bbox.max.Y)) / 2.0,
        -float(bbox.min.Z),
    )


def build_coupon(config: CouponConfig) -> tuple[Compound, Shape, Shape, list[Shape], list[Shape]]:
    if len(config.guide_variants_mm) != len(STATION_X_MM):
        raise ValueError("Exactly five guide variants are required")
    if len(config.pocket_variants_mm) != len(STATION_X_MM):
        raise ValueError("Exactly five pocket variants are required")

    positives: list[Shape] = [Box(BASE_X_MM, BASE_Y_MM, BASE_Z_MM, align=(Align.MIN, Align.MIN, Align.MIN))]
    label_z = BASE_Z_MM - 0.05

    for index, (x, guide) in enumerate(zip(STATION_X_MM, config.guide_variants_mm)):
        positives.append(build_cradle_station(config, x, GUIDE_ROW_Y_MM))
        positives.extend(raised_label(f"G{guide:.2f}", x, 29.0, label_z))
        if index == 2:
            positives.extend(seed_label_frame(x, 29.0, label_z))

    for index, (x, pocket) in enumerate(zip(STATION_X_MM, config.pocket_variants_mm)):
        positives.append(build_pocket_fit_cell(pocket, x, POCKET_ROW_Y_MM))
        positives.extend(raised_label(f"P{pocket:.2f}", x, 4.0, label_z))
        if index == 2:
            positives.extend(seed_label_frame(x, 4.0, label_z))

    levels = mechanism_levels(config)
    for x in RETAINER_X_MM:
        positives.append(
            moved(
                Cylinder(
                    RETAINER_BOSS_DIAMETER_MM / 2.0,
                    levels["deckBottom"] - BASE_Z_MM + 0.10,
                    align=(Align.CENTER, Align.CENTER, Align.MIN),
                ),
                x,
                GUIDE_ROW_Y_MM,
                BASE_Z_MM - 0.10,
            )
        )

    base = fuse_all(positives, "BUTTON_FDM_TEST_COUPON_BASE_POSITIVE")
    pilot_cutters = [
        moved(
            Cylinder(
                RETAINER_PILOT_DIAMETER_MM / 2.0,
                levels["deckBottom"] + 0.20,
                align=(Align.CENTER, Align.CENTER, Align.MIN),
            ),
            x,
            GUIDE_ROW_Y_MM,
            -0.10,
        )
        for x in RETAINER_X_MM
    ]
    base = subtract_all(base, pilot_cutters, "BUTTON_FDM_TEST_COUPON_BASE_AND_CRADLES")
    if len(base.solids()) != 1:
        raise RuntimeError(f"Coupon base must remain connected, got {len(base.solids())} solids")

    # The assembled top face is placed on the print bed.  After printing, flip
    # the deck over; every shoulder pocket was therefore printed open upward.
    deck_print = build_guide_deck(config).rotate(Axis.X, 180.0)
    deck = place_on_bed(deck_print, BASE_X_MM / 2.0, DECK_PRINT_ROW_Y_MM)
    deck.label = "GUIDE_DECK_TOP_FACE_DOWN__FLIP_AFTER_PRINT"

    caps: list[Shape] = []
    for index, x in enumerate(STATION_X_MM):
        # Rebuild each repeated part so STEP retains distinct child metadata.
        cap_print = build_cap(config).rotate(Axis.X, 180.0)
        cap = place_on_bed(cap_print, x, CAP_PRINT_ROW_Y_MM)
        cap.label = f"CAP_{index + 1}_TAIL_{config.cap_tail_diameter_mm:.2f}"
        caps.append(cap)

    clips: list[Shape] = []
    for index, x in enumerate(STATION_X_MM):
        clip = place_on_bed(build_retention_clip(), x, CLIP_PRINT_ROW_Y_MM)
        clip.label = f"CAP_RETENTION_C_CLIP_{index + 1}"
        clips.append(clip)

    plate = Compound(children=[base, deck, *caps, *clips], label="BUTTON_FDM_TEST_COUPON_V2_PRINT_LAYOUT")
    return plate, base, deck, caps, clips


def volume(shape: Shape | None) -> float:
    return float(shape.volume) if shape is not None and shape.solids() else 0.0
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

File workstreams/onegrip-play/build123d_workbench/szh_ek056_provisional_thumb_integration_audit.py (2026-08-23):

"""Provisional SZH-EK056 packaging audit against the frozen 8-button baseline.

This is deliberately an analysis-only, single-process job.  It creates no
production STEP/STL, never edits the frozen Finger/Thumb geometry, and uses the
full JaD/JfD B-reps only once each to derive a small local crop.
"""

from __future__ import annotations

from datetime import datetime, timezone
import gc
import hashlib
import itertools
import json
import math
import os
from pathlib import Path
from typing import Iterable

import numpy as np
import psutil
from build123d import Align, Box, Compound, Cylinder, Location, Plane, Shape, Sphere, Vector, import_step

from .finger_controls_v2 import ControlDatum, point_at, unit, xyz
from .model import oriented_box_between
from .n2_production_intent_mechanism import FRONT_DEPTH_MM as N2_FRONT_DEPTH_MM
from .option_c_local_exact_prototype import (
    datum_from_manifest,
    modified_n2,
    raster_scene,
    safe_edge_lines,
    safe_triangles,
)
from .original_thumb_module_reuse_audit import load_target_parts
from .real_integration_conflict_resolution import terminal_path
from .szh_ek056_web_reference import (
    HEADER_PIN_COUNT,
    HEADER_PIN_D,
    HEADER_X_MAX,
    HEADER_Y_CENTRE,
    HEADER_Z_CENTRE,
    JOY_X,
    JOY_Y,
    MAX_TILT_DEG,
    MOUNT_HOLE_CENTRES,
    MOUNT_HOLE_D,
    PIVOT_Z,
    build_reference,
)


ROOT = Path(__file__).resolve().parents[1]
OUT_DIR = ROOT / "build123d_workbench" / "out" / "szh_ek056_provisional_thumb_integration_audit"
RENDER_DIR = ROOT / "renders" / "szh_ek056_provisional_thumb_integration_audit"
JSON_PATH = OUT_DIR / "szh_ek056_provisional_thumb_integration_audit.json"
REPORT_PATH = ROOT / "docs" / "71_szh_ek056_provisional_thumb_integration_audit.md"

REFERENCE_STEP = ROOT / "local_cad" / "reference" / "SZH_EK056_WEB_REFERENCE.step"
REFERENCE_JSON = ROOT / "local_cad" / "reference" / "SZH_EK056_WEB_REFERENCE.json"
REFERENCE_RESEARCH = ROOT / "docs" / "szh_ek056_cad_reference_research.md"
PIN_LABEL_IMAGE = (
    ROOT / "lower_adapter" / "local_cad" / "reference" / "szh_ek056_web"
    / "ps_Joystick-Module-Connections-1.jpg"
)
MANIFEST = ROOT / "build123d_workbench" / "out" / "finger_controls_v2" / "finger_controls_v2_source_manifest.json"
OPTION_C_SOURCE = ROOT / "build123d_workbench" / "out" / "option_c_final_local_fit" / "OPTION_C_FINAL_LOCAL_FIT.step"
N2_ASSEMBLY = ROOT / "build123d_workbench" / "out" / "n2_production_intent_mechanism" / "N2_PRODUCTION_INTENT_LOCAL_ASSEMBLY.step"
N1_N2_CARRIER = ROOT / "build123d_workbench" / "out" / "n1_production_intent_mechanism" / "N1_N2_SHARED_CARRIER_N1_LOCAL.step"
I2_I3_CARRIER = ROOT / "build123d_workbench" / "out" / "i2_i3_production_intent_mechanism" / "I2_I3_SHARED_CARRIER_PRODUCTION_INTENT_LOCAL.step"
M4_N3_CARRIER = ROOT / "build123d_workbench" / "out" / "m4_n3_production_intent_mechanism" / "M4_N3_SHARED_CARRIER_PRODUCTION_INTENT_LOCAL.step"
I4_CARRIER = ROOT / "build123d_workbench" / "out" / "real_integration_conflict_resolution" / "I4_CARRIER_LOCAL_MANUFACTURING_RELIEF.step"
M3_CARRIER = ROOT / "build123d_workbench" / "out" / "i4_m3_production_intent_mechanisms" / "M3_CARRIER_PRODUCTION_INTENT_LOCAL.step"
M4_N3_TERMINALS = ROOT / "build123d_workbench" / "out" / "m4_n3_terminal_redundancy_resolution" / "M4_N3_TRIMMED_TERMINALS_LOCAL_REFERENCE.step"
JAD_SHELL = ROOT / "build123d_workbench" / "out" / "finger_controls_v2" / "JAD_FINGER_V2.step"
JFD_SHELL = ROOT / "build123d_workbench" / "out" / "finger_controls_v2" / "JFD_FINGER_V2.step"
DOC70 = ROOT / "docs" / "70_finger_8_button_mechanical_baseline_checkpoint.md"

BOOLEAN_EPS_MM3 = 1.0e-6
NEAR_EXACT_DISTANCE_MM = 4.0
WIRE_DIAMETER_MM = 1.30
WIRE_INITIAL_LENGTH_MM = 7.0
SOLDER_DIAMETER_MM = 1.60
RSS_LIMIT_MB = 24576.0
AVAILABLE_STOP_MB = 3072.0

# Approved original joystick datum from the preceding local exact Thumb work.
DATUM_P = np.asarray((-0.21604013507035, -23.14907664213591, 40.49617911468703), float)
DATUM_N = unit(np.asarray((-0.000181853768751, -0.598493368976127, -0.801127739015953), float))
DATUM_U = unit(np.asarray((0.99999946034044, 0.000710605462944, -0.000757864568375), float))
DATUM_V = unit(np.asarray((0.001022862666615, -0.801127444500238, 0.598492916767178), float))
OUTWARD = -DATUM_N

PROCESS = psutil.Process(os.getpid())
MEMORY: list[dict[str, object]] = []

COLORS = {
    "pcb": (42, 151, 102),
    "gimbal": (188, 198, 207),
    "x_pot": (239, 113, 67),
    "y_pot": (70, 152, 224),
    "push_switch": (239, 233, 205),
    "shaft": (241, 196, 76),
    "cap": (66, 73, 84),
    "header": (193, 102, 214),
    "pins": (220, 174, 72),
    "roots": (74, 205, 165),
    "carrier": (96, 182, 220),
    "switch": (232, 132, 72),
    "terminals": (248, 197, 74),
    "shell": (81, 162, 187),
    "collision": (255, 51, 71),
    "hw504": (164, 106, 227),
    "wire_rear": (235, 88, 87),
    "wire_side": (65, 195, 145),
    "wire_wall": (64, 145, 230),
    "moving": (255, 144, 65),
    "attachment": (196, 204, 211),
    "backplate": (128, 136, 148),
}


def memory(stage: str) -> None:
    gc.collect()
    rss = float(PROCESS.memory_info().rss) / (1024.0 * 1024.0)
    available = float(psutil.virtual_memory().available) / (1024.0 * 1024.0)
    MEMORY.append({"stage": stage, "rssMb": round(rss, 1), "systemAvailableMb": round(available, 1)})
    if rss > RSS_LIMIT_MB:
        raise MemoryError(f"RAM safety stop at {stage}: process RSS {rss:.1f} MB")
    if available < AVAILABLE_STOP_MB:
        raise MemoryError(f"RAM safety stop at {stage}: system available {available:.1f} MB")


def sha256(path: Path) -> str:
    digest = hashlib.sha256()
    with path.open("rb") as stream:
        for block in iter(lambda: stream.read(1024 * 1024), b""):
            digest.update(block)
    return digest.hexdigest()


def bbox(shape: Shape) -> dict[str, list[float]]:
    b = shape.bounding_box()
    return {
        "min": [float(b.min.X), float(b.min.Y), float(b.min.Z)],
        "max": [float(b.max.X), float(b.max.Y), float(b.max.Z)],
    }


def bbox_gap(left: Shape, right: Shape) -> float:
    a = left.bounding_box()
    b = right.bounding_box()
    gaps = np.asarray(
        (
            max(0.0, float(a.min.X - b.max.X), float(b.min.X - a.max.X)),
            max(0.0, float(a.min.Y - b.max.Y), float(b.min.Y - a.max.Y)),
            max(0.0, float(a.min.Z - b.max.Z), float(b.min.Z - a.max.Z)),
        ),
        float,
    )
    return float(np.linalg.norm(gaps))


def shape_center(shape: Shape) -> np.ndarray:
    b = shape.bounding_box()
    return np.asarray((0.5 * (b.min.X + b.max.X), 0.5 * (b.min.Y + b.max.Y), 0.5 * (b.min.Z + b.max.Z)), float)


def point_world(local: Iterable[float], origin: np.ndarray) -> np.ndarray:
    x, y, z = [float(value) for value in local]
    return origin + DATUM_V * x + DATUM_U * y + OUTWARD * z
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

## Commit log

2026-08-08 딸깍 설계 구체화 v1
    제7회 국립재활원 보조기기 해커톤 · 한 손 전용 통합 입력장치
    - 엄지 자원 충돌 해소: 손바닥 반대편 5키 폐지, 드래그락 + 원샷 모디파이어
    - 한글 입력 경로 확정: 천지인 파생 배열 → 두벌식 스캔코드 변환 (드라이버 불필요)
    - 3레이어 키맵, 기구 치수, BOM, 펌웨어 구조, 검증 계획
    개인정보(팀원 연락처·주소) 포함 초안 docx 2건은 .gitignore로 제외
    Claude-Session: https://claude.ai/code/session_01D9q87FhBDxXNTv7DP9JMfR
2026-08-08 README 추가 — 팀 공유용 개요 및 결정 대기 항목
    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
2026-08-08 수요자 멘토링 질문지 추가
    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
2026-08-08 설계 대안 추가 — Half-QWERTY 방식
    중도장애 사용자의 기존 QWERTY 근육기억을 재사용하는 미러 방식.
    Matias et al. 1993 실측치 기반. v1의 위험 3개(방향 입력 분리운동,
    IME 조합 엔진 OS 의존성, 배열 학습 부담)를 동시에 해소.
    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
2026-08-08 누운 자세 사용자 구체화 — Track A/B 분기
    Track A(손가락 자유·팔 못 듦)는 입력부 재사용, 거치 시스템만 신규.
    Track B(손가락 미세조작 불가)는 사실상 별도 제품, 조이스틱+OS 화상 키보드.
    공통 코어 + 교체 셸 3종 구조 제안.
    누운 자세가 신청서 필수/확장 범위를 뒤집음: BLE 필수화, LED→햅틱.
    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
2026-08-15 게임기기 전환 정리 — B안(딸깍 게이밍) 확정
    한 손 키보드에서 한 손 게임 입력장치로 방향을 바꾸면서 흩어진 문서를 정리하고,
    충돌하던 두 설계안 중 B안을 확정했다.
    설계 결정
    - B안 확정: 플라이트스틱 · XIAO nRF52840 단독 · Switch + PC · 유선 USB-C
    - A안(OneGrip Play, ESP32-S3+Pico+Brook, PS4 포함) 폐기 → archive/onegrip-a/
    - 제품명을 딸깍으로 통일 (OneGrip Play 폐기)
    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
    [hard_stop_shim_profile.dxf]
2026-08-15 README: 커밋 상태 반영
    Claude-Session: https://claude.ai/code/session_013P5vRA4oTXVESGNZEVe5Fa
2026-08-16 8/16 정리 — 폐기 문서 제거, B안 폼팩터 레퍼런스 추가
    B안(딸깍 게이밍) 확정으로 전제가 끝난 문서를 작업 트리에서 뺐다.
    히스토리에는 전부 남아 있고 README §8에 복구 명령을 적었다.
    제거
    - archive/keyboard-era/ 7개 — 한 손 키보드 시절
    - archive/onegrip-a/완전구현_설계및부품안.md — A안 본문(8/13)
    - 계획및부품안.md, 보조기기_국내빠른조달_26입력_부품리스트_v4.md
    — 팀원이 올린 A안 계열(8/9), 위 문서의 이전 판
    - ppt/*.pptx, ppt/제7회~1.PPT 4개 — 전부 키보드 시절 "신청서 수정사항 보고" 덱
    - ppt/deck.js.bak, .DS_Store, ppt/*.preview.html
    추가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
2026-08-21 Initial OneGrip Play CAD workspace
    [Joystick - Backplate.stl, Joystick - Button_corner_1.stl, Joystick - Button_corner_2.stl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]
2026-08-21 Add current OneGrip Play CAD workspace
    [Joystick - Backplate.stl, Joystick - Button_corner_1.stl, Joystick - Button_corner_2.stl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]
2026-08-21 Add embedded gimbal chassis cleanup validation
2026-08-21 Add chassis cleanup validation
2026-08-22 Sync latest OneGrip Play workspace
    [BALLAST_BAY_DEMO.step, BALLAST_BAY_DEMO.stl, BOTTOM_CARRIER_FINAL.step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]
2026-08-23 Checkpoint complete OneGrip Play workspace through docs 72
    [ARMREST_CUSTOM_SUPPORT_PLA.step, ARMREST_CUSTOM_SUPPORT_PLA.stl, ARMREST_CUSTOM_SUPPORT_PLA_V1.step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]
